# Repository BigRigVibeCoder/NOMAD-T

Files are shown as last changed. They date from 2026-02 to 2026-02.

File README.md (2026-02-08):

# NOMAD-T

**Autonomous Off-Road UGV — Engineering Design Package**

A field-hardened, 4WD skid-steer robot built from mass-produced scooter components. Designed for outdoor autonomy in unstructured terrain.

> **Architecture Lock (Rev 4.0):** Rigid 2040 frame, 4× Ninebot G30 hub motors, 36V Li-Ion, Odroid H4 Ultra.

---

## Versions

| Version | Codename | Purpose | Motors | Budget | Status |
|:---|:---|:---|:---|:---|:---|
| **Mk.0 "Scrapper"** | Alpha | Cheap pavement testbed | 4× Hoverboard 6.5" | ~$460 | **ACTIVE** |
| **Mk.1 "Nomad"** | Release | Field-hardened, weatherproof | 4× Ninebot G30 | ~$1,500 | Design Complete |

---

## Key Specifications

| Parameter | Value |
|:---|:---|
| **Drivetrain** | 4× Ninebot Max G30 Rear Hub Motors (Direct Drive) |
| **Frame** | 2040 V-Slot Aluminum Extrusion, 700 × 320mm |
| **Wheels** | 10" G30 Pneumatic (60/70-6.5), Tubeless |
| **Suspension** | None (Rigid) — Pneumatic tires provide damping |
| **Compute** | Odroid H4 Ultra (Intel i3-N305, 8C, DDR5) |
| **Sensors** | RPLiDAR C1, OAK-D Lite, 4× Sharp IR, BNO085 IMU |
| **Power** | 10S3P Li-Ion (36V), DDR-60L-15 DC-DC (17V Logic) |
| **Safety** | 60A MIDI Fuse, E-Stop, Arduino Watchdog, Contactor |
| **Enclosure** | Apache 3800 (IP65) on Vibration Isolation Bobbins |
| **Weight** | ~19 kg |
| **Est. Cost** | ~$1,600 |

---

## Project Structure

```
00_ALPHA/          Mk.0 "Scrapper" prototype specs & BOM
01_PROTOCOLS/      Documentation standards & naming conventions (HM-PRO)
02_CATALOG/        Mk.1 component specs, BOMs, trade studies (HM-CAT)
03_OPERATIONS/     Build guides, safety manual, checklists (HM-OPS)
04_ASSETS/         Images, renders, CAD models (HM-AST)
05_RESEARCH/       Analysis, whitepapers, CDR findings (HM-RES)
06_ENGINEERING/    Schematics, tools, source code (HM-DWG/SRC)
```

---

## Document Index

### Alpha (Mk.0 "Scrapper")
| ID | Title |
|:---|:---|
| HM-ALPHA-001 | [Alpha Prototype Spec](00_ALPHA/HM-ALPHA-001_spec.md) |
| HM-ALPHA-002 | [Alpha BOM / Shopping List](00_ALPHA/HM-ALPHA-002_bom.md) |

### Protocols
| ID | Title |
|:---|:---|
| HM-PRO-001 | [Documentation Standards](01_PROTOCOLS/HM-PRO-001_doc_standards.md) |

### Specifications (Catalog)
| ID | Title |
|:---|:---|
| HM-CAT-001 | [Master Design (Phase 1)](02_CATALOG/HM-CAT-001_master_design.md) |
| HM-CAT-002 | [Shopping List](02_CATALOG/HM-CAT-002_shopping_list.md) |
| HM-CAT-003–008 | Sensor Datasheets (OAK-D, PZEM, IR, LiDAR, GNSS, IMU) |
| HM-CAT-009 | [Brain Core (Odroid H4 Ultra)](02_CATALOG/HM-CAT-009_brain_core_compute.md) |
| HM-CAT-010 | [Drivetrain (G30 Hub Motors)](02_CATALOG/HM-CAT-010_drivetrain_spec.md) |
| HM-CAT-011 | [Component Trade Studies](02_CATALOG/HM-CAT-011_cots_selection.md) |
| HM-CAT-012 | [Master Integration (Apache 3800)](02_CATALOG/HM-CAT-012_master_integration.md) |
| HM-CAT-013 | [Frame (Rigid 2040)](02_CATALOG/HM-CAT-013_frame_suspension.md) |
| HM-CAT-014 | [Electrical System (36V)](02_CATALOG/HM-CAT-014_electrical_system.md) |
| HM-CAT-015 | [Custom Parts (Motor Plate NMT-MP-001)](02_CATALOG/HM-CAT-015_custom_parts.md) |
| HM-CAT-016 | [Odroid H4 Ultra Datasheet](02_CATALOG/HM-CAT-016_odroid_h4_ultra_datasheet.md) |

### Operations
| ID | Title |
|:---|:---|
| HM-OPS-001 | [Build Manual](03_OPERATIONS/HM-OPS-001_build_manual.md) |
| HM-OPS-002 | [Safety Manual](03_OPERATIONS/HM-OPS-002_safety_manual.md) |
| HM-OPS-003 | [Pre-Flight Checklist](03_OPERATIONS/HM-OPS-003_preflight_checklist.md) |

### Research
| ID | Title |
|:---|:---|
| HM-RES-001 | [Nomad-T Concept Analysis](05_RESEARCH/HM-RES-001_nomad_t_analysis.md) |
| HM-RES-002 | [UGV Whitepaper](05_RESEARCH/HM-RES-002_ugv_whitepaper.md) |
| HM-RES-003 | [Pre-Build Research Questions (Rev 4.0)](05_RESEARCH/HM-RES-003_pre_build_research_questions.md) |
| HM-RES-004 | [Case Selection Study](05_RESEARCH/HM-RES-004_case_selection_study.md) |
| HM-RES-005 | [Critical Design Review (13 CDRs)](05_RESEARCH/HM-RES-005_critical_design_review.md) |
| HM-RES-006 | [Hub Motor Trade Study](05_RESEARCH/HM-RES-006_hub_motor_trade_study.md) |

### Engineering
| ID | Title |
|:---|:---|
| HM-DWG-001 | [Wiring Harness Schematic](06_ENGINEERING/01_SCHEMATICS/HM-DWG-001_wiring_harness.md) |

---

## Status

**Phase 1 Hardware Design: COMPLETE**
- All 13 Critical Design Reviews resolved
- Wiring harness schematic issued
- Documentation synchronized
- Ready for procurement and assembly

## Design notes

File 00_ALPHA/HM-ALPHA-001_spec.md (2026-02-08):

---
ID: HM-ALPHA-001
Status: ACTIVE
Version: Mk.0 "Scrapper"
Date: 2026-02-08
Role: Alpha Prototype Specification
Linked: HM-CAT-001 (Mk.1 Master)
---

# Nomad-T Mk.0 "Scrapper" — Alpha Prototype Specification

> [!NOTE]
> **Purpose:** Cheapest possible skid-steer testbed to prove the ROS 2 control stack, VESC CAN bus, and autonomy software BEFORE committing to the $1,500 Mk.1 field build.
>
> **Constraints:** Pavement only. No weatherproofing. Budget: **<$500.**

---

## 1. System Overview

| Parameter | Mk.0 "Scrapper" | Mk.1 "Nomad" (Future) |
|:---|:---|:---|
| **Motors** | 4× Hoverboard 6.5" (Salvaged) | 4× Ninebot G30 |
| **Tires** | 6.5" Solid Rubber | 10" Pneumatic |
| **Frame** | 2040 V-Slot (700×320mm) | Same |
| **Voltage** | 36V (10S) | Same |
| **VESCs** | 4× Flipsky 75100 | Same |
| **Compute** | Odroid H4 Ultra | Same |
| **Enclosure** | Open-top (no case) | Apache 3800 (IP65) |
| **Waterproofing** | ❌ None | ✅ IPX5 |
| **Ground Clearance** | ~50mm | ~89mm |
| **Weight** | ~14 kg | ~19 kg |
| **Budget** | **~$458** | ~$1,500 |

---

## 2. Motor: Hoverboard 6.5" BLDC (Salvaged)

### Sourcing
**Buy 2× broken hoverboards** from Facebook Marketplace, Craigslist, or thrift stores.

- **Target price:** $10-20 per board = **$20-40 total for 4 motors**
- **What breaks on hoverboards:** Battery (dead cells), main board (blown FETs), charger port. **Motors almost never fail.**
- **What you harvest:** 2× BLDC hub motors with tires, Hall sensor cables, phase wires

### Specs

| Spec | Value |
|:---|:---|
| **Type** | Brushless DC (BLDC), direct drive |
| **Power** | 250–350W rated |
| **Voltage** | 36V (10S) — Native! |
| **Torque** | ~12 Nm per motor |
| **Tire** | 6.5" solid rubber (bonded) |
| **Hall Sensors** | Yes (5-wire: VCC, GND, HA, HB, HC) |
| **Phase Wires** | 3× (Match or auto-detect in VESC Tool) |
| **Weight** | ~2.3 kg per motor+tire |

### VESC Compatibility

> [!TIP]
> Hoverboard motors are one of the most common VESC targets. VESC Tool has built-in motor detection that auto-configures phase order and Hall sensor mapping. **No manual configuration needed** — just run "Detect Motor" wizard.

---

## 3. Mounting Strategy

Hoverboard motors have **no external axle**. They bolt directly to a frame via 4× M4 threaded holes on the motor face.

### Option A: 3D Printed Bracket (Fastest)
- **Material:** PETG or Nylon (100% infill)
- **Design:** L-bracket bolting motor face to 2040 rail side slot
- **Lifespan:** ~50 hours. Fine for prototyping.
- **Cost:** ~$2 in filament

### Option B: Flat Aluminum Bracket (Durable)
- **Material:** 3mm aluminum flat bar
- **Design:** Bent L-bracket, drilled on both ends
- **Cost:** ~$5 from hardware store
- **Upgradeable:** Can use same bracket concept for Mk.1 motor plates

---

## 4. Electrical (Simplified)

The Mk.0 uses the **same 36V architecture** as Mk.1 but with simplified wiring:

| System | Mk.0 Approach | Mk.1 Equivalent |
|:---|:---|:---|
| **Battery** | Salvaged hoverboard 36V pack OR cheap e-bike 10S pack | Custom 10S3P |
| **Main Fuse** | 40A blade fuse (cheaper) | 60A MIDI fuse |
| **DC-DC** | DDR-60L-15 (17V) | Same |
| **Safety** | E-Stop + basic relay | Full safety chain |
| **CAN Bus** | Daisy chain (same) | Same |
| **Contactor** | Optional (can use E-Stop direct for <40A) | 100A Contactor |

### Simplified Wiring

```
Battery (36V) → Blade Fuse (40A) → E-Stop → Bus Bar
  ├── VESC 1 (Front Left)
  ├── VESC 2 (Front Right)
  ├── VESC 3 (Rear Left)
  ├── VESC 4 (Rear Right)
  └── DC-DC (17V) → Odroid H4 Ultra
```

---

## 5. What to Test on Mk.0

| Test | Goal | Pass Criteria |
|:---|:---|:---|
| **VESC Motor Detection** | All 4 motors detected | Spin freely, correct direction |
| **CAN Bus Daisy Chain** | All 4 VESCs communicate | `ros2 topic echo` shows all 4 |
| **Teleop (RC)** | Joystick controls skid steer | Smooth forward, reverse, turn |
| **Turn-in-Place** | Zero-radius turn on pavement | Completes 360° without slipping |
| **Odometry** | Hall sensor ticks = distance | Straight line ±5% over 10m |
| **E-Stop** | Kill switch works | Motors stop within 0.5s |
| **Watchdog** | Software crash = motors off | Unplug USB → motors stop |

---

## 6. Upgrade Path: Mk.0 → Mk.1

When Mk.0 has proven the software stack:

1. **Unbolt** hoverboard motors + 3D printed brackets
2. **Bolt on** G30 motor plates (NMT-MP-001)
3. **Slide in** G30 hub motors
4. **Swap** blade fuse → MIDI fuse holder
5. **Add** Apache 3800 case on bobbins
6. **Add** Contactor + full safety chain
7. **Replace** salvaged battery → proper 10S3P pack

**Everything else stays.** Frame, VESCs, Odroid, DC-DC, CAN — all identical.

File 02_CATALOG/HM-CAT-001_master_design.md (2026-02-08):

---
ID: HM-CAT-001
Status: ACTIVE
Role: Master Design Specification (Phase 1)
Date: 2026-02-07
Linked: HM-CAT-010, HM-CAT-012, HM-CAT-013, HM-CAT-014
---

# Nomad-T Phase 1 "Skid-Steer" Specification

> [!NOTE]
> **APPROVED DESIGN.** This document supersedes all previous concepts (Badger-M, Arrma, Suspension).
> **Objective:** Build a rugged, weatherproof, skid-steer field robot using mass-produced scooter components.

## 1. System Overview

*   **Architecture:** 4WD Skid-Steer (Tank Drive)
*   **Chassis:** Rigid 2040 Aluminum Extrusion with DiBond Shear Panels
*   **Drivetrain:** 4× Direct-Drive Hub Motors (Ninebot G30 Gen 2)
*   **Power:** 36V 10S3P Li-Ion (Swappable)
*   **Compute:** Odroid H4 Ultra (x86) + OAK-D Lite + RPLiDAR C1
*   **Target Mass:** ~18–22kg
*   **Payload:** ~10kg (Flat Deck)
*   **Speed:** ~25 km/h (Software limited)

## 2. Core Directives (from CDR)

1.  **"Golden Unit" Sourcing:** Use verified OEM/refurb parts for critical drivetrain components (G30 motors), not generic clones.
2.  **Unified Thermal Deck:** The Odroid and VESCs share a common 6mm aluminum armor plate for cooling and protection (CDR-4).
3.  **Vibration Isolation:** The electronics case (Apache 3800) is "floated" on rubber bobbins to protect components (CDR-3).
4.  **Hardware Safety:** Physical E-Stop loop, independent status LEDs, and hardware watchdog (CDR-6, CDR-12).

## 3. Subsystem Breakdown

### 3.1 Structure (HM-CAT-013)
*   **Rails:** 700mm long 2040 V-Slot (Silver).
*   **Width:** 320mm outer-to-outer.
*   **Panels:** 3mm DiBond (Aluminum Composite) side skins for shear strength.
*   **Waterproofing:** IP65 desired for case (IPX5 for motors).

### 3.2 Drivetrain (HM-CAT-010)
*   **Motors:** 4× Ninebot Max G30 Rear Hub Motors (350W nom / 800W peak).
*   **Tires:** 10" Pneumatic (60/70-6.5) Pre-installed.
*   **Mounting:** Custom 6mm Aluminum plates with 2mm fillet radii slots (CDR-2).

### 3.3 Electronics (HM-CAT-014 & HM-DWG-001)
*   **Voltage:** 36V Nominal (10S).
*   **Protection:** 60A MIDI Fuse (Main), 10A (Charge), 5A (DC-DC).
*   **Logic:** 17V regulated for Odroid (CDR-8).
*   **Control:** 4× Flipsky 75100 VESC via CAN Bus.

## 4. Bill of Materials Summary (Phase 1)

| Subsystem | Est. Cost | Status |
| :--- | :--- | :--- |
| **Drivetrain** (Motors, Plates) | ~$350 | Sourcing |
| **Structure** (Rails, Case, DiBond) | ~$150 | Sourcing |
| **Power** (Battery, Fuse, Wiring) | ~$200 | Sourcing |
| **Compute** (Odroid, RAM, WiFi) | ~$400 | Purchased |
| **Control** (VESCs, Arduino) | ~$300 | Sourcing |
| **Sensors** (LiDAR, Camera) | ~$250 | Sourcing |
| **Total** | **~$1,650** | **Under Budget ($2k)** |

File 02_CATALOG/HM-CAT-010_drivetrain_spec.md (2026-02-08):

---
ID: HM-CAT-010
Status: ACTIVE
Role: Drivetrain Specification
Date: 2026-02-07
Linked: HM-CAT-001 (Master), HM-CAT-013 (Frame)
---

# Drivetrain Specification

> [!NOTE]
> **Design Change:** Shifted from "Belt Drive Outrunner" to **Direct Drive Hub Motor** for reliability, waterproofing, and simplicity.

## 1. Selected Motor: Ninebot Max G30 (Gen 2)

*   **Type:** Brushless Direct Drive Hub Motor
*   **Position:** Rear Wheel (Drum brake compatible, though brake not strictly required)
*   **Voltage:** 36V Nominal (10S)
*   **Power:** 350W Nominal / 700W Peak
*   **Torque:** ~30 Nm peak per wheel (×4 = 120 Nm total)
*   **KV:** ~14 KV (High torque, low speed)
*   **Speed:** ~30 km/h unloaded at 36V

### 1.1 Sourcing Rules (The "Golden Unit" - CDR-1)
*   **Target:** OEM or High-Quality Refurb (MonsterScooterParts, reputable eBay pulls).
*   **Avoid:** "Front" wheels (no motor), "Lite" versions (G30L/LP).
*   **Connector:** 3× Phase (Bullet/Spade) + 5/6 pin Hall Sensor.
    *   *Action:* Likely need to re-terminate phase wires to 4mm Bullets or MR60 for VESC.

## 2. Tire Specification

*   **Size:** 10 inch (Nominal OD ~250mm)
*   **Format:** 60/70-6.5 Tubeless Pneumatic
*   **Pressure:** ~25-30 PSI (Lower for off-road traction)
*   **Self-Healing:** Many G30 tires come with internal sealant (gel layer). This is a **bonus** for field robustness.

## 3. Mounting Interface (CDR-2 Specification)

> [!CRITICAL]
> **Custom Part Required:** NMT-MP-001 Motor Plate

The G30 axle has a "Double-D" profile. It **cannot** be clamped in standard round mounts.

*   **Plate Material:** 6061-T6 Aluminum (6mm thick).
    *   *Upgrade Option:* 304 Stainless Steel (CDR-2 recommendation for fatigue).
*   **Axle Slot:** 12mm Round with 10mm Flats.
*   **Fillet Radius:** **R2.0mm minimum** in slot corners to prevent stress risers.
*   **Fastening:** Bolted to 2040 Extrusion end-face via 4× M5 screws.
*   **Anti-Rotation:** The tight-tolerance slot + torque washer prevents axle spin.

## 4. Performance Calculations

| Param | Value |
| :--- | :--- |
| **Simulated Speed** | ~25 km/h (Loaded) |
| **Traction Force** | ~400N (continuous) / ~1000N (peak) |
| **Climbing Grade** | >30% (Skid steer traction limited) |
| **Turn-in-Place** | Excellent (High torque, rigid chassis) |

## 5. Maintenance Schedule (CDR-1)

*   **Bearings:** 6001-2RS (Standard sealed).
    *   *Interval:* Check for play every 50km. Replace if gritty.
*   **Axle Nuts:** Check torque (tightness) every 10 hours of operation.
*   **Tire Pressure:** Check weekly.

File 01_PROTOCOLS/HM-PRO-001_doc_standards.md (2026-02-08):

# Protocol: HiveMind Documentation Standard
**ID:** HM-PRO-001
**Status:** ACTIVE
**Classification:** OPEN INTERNAL

## 1. Purpose
To establish a high-assurance, "Deep Tech" documentation framework that ensures traceability, version control compatibility, and ease of cognitive retrieval for the Nomad-T project.

## 2. Directory Structure (Johnny Decimal + Diataxis)
The project structure determines the *type* of information stored.

*   **01_PROTOCOLS (Reference - Laws)**
    *   Standards, conventions, and defining rigid rules.
    *   *Example:* This document (`HM-PRO-001`).
*   **02_CATALOG (Reference - Specs)**
    *   System Specifications, Bill of Materials (BOM), and "Recipes".
    *   *Example:* Master Design Specs, Shopping Lists.
*   **03_OPERATIONS (How-to - Guides)**
    *   Step-by-step instructions, assembly guides, and tutorials.
    *   *Example:* "How to mount the motor", "Wiring Guide".
*   **04_ASSETS (Media)**
    *   Binary assets, Images, CAD files, Drawings.
*   **05_RESEARCH (Explanation)**
    *   Whitepapers, Trade Studies, Analysis, and theoretical groundwork.
*   **06_ENGINEERING (Source)**
    *   Technical source files, Schematics, Firmware, and Python tools.
    *   *Example:* Wiring Diagrams (HM-DWG), Source Code (HM-SRC).

## 3. Identification System (HM-ID-XXX)
All documentation files must have a unique identifier in their filename to ensure traceability despite refactors.

**Format:** `HM-[TYPE]-[SEQ]_[snake_case_title].md`

### Types
*   **PRO:** Protocol (Standards, Rules)
*   **CAT:** Catalog (Specs, Parts)
*   **OPS:** Operations (Guides, Manuals)
*   **RES:** Research (Theory, Analysis)
*   **DWG:** Drawing (Schematics, Diagrams)
*   **SRC:** Source Code (Firmware, Software)
*   **AST:** Asset (Images, Models) - *Mandatory for release candidates*

### Sequence
*   3-Digit Integer (e.g., `001`, `002`).
*   Sequences are unique *per Type*.

## 4. Maintenance
*   **Docs-as-Code:** All docs are stored in the repo with the code/designs.
*   **Traceability:** Changes to design must reference the Protocol or Catalog ID they affect.
*   **Assets:** All assets must be numbered (HM-AST-XXX) to be referenced in specs.

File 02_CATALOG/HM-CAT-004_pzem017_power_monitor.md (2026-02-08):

---
ID: HM-CAT-004
Status: ACTIVE
Source: github.com/BigRigVibeCoder/HiveMind
---

# Component Specification: Main Power & Energy Monitor

**Role:** Metabolic Analysis (Voltage, Current, Power, Energy Consumption)

**Hardware:** Peacefair PZEM-017 (Industrial DC)

**Interface:** RS485 (via USB Adapter)

## 1. The Problem: Measuring "The Gulp"

The robot's motors draw power in violent spikes (0A to 20A in milliseconds).

- **INA219 (Standard):** Max 3.2A. **REJECTED.** It will burn out.

- **Voltage Dividers:** Inaccurate. Only gives voltage, not current.

We need a sensor that can handle **60A Continuous / 80A Peak** at **36V** (10S Li-Ion, 30–42V range).

## 2. The Solution: PZEM-017 (Industrial DC Meter)

*Best for Phase 2/3 "Coyote". Zero soldering. Includes USB Interface.*

### 2.1 Hardware Overview

- **Type:** DC Communication Box + External Shunt.

- **Range:** 0-300V, 0-300A (Configurable based on shunt).

- **Interface:** RS485 (Modbus-RTU).

- **Isolation:** High voltage side is opto-isolated from the communication side. (Protects the Odroid USB port from spikes).

### 2.2 Integration Strategy

1. **Shunt:** Bolt the **100A / 75mV Shunt** onto the **36V HV Bus**.

   - **Location:** Between the 60A MIDI Fuse and the Distribution Bus (see HM-DWG-001).

   - **Orientation:** "Load" side goes to contactor/VESCs.

2. **Sense Wires:** Run small wires from the Shunt screws to the PZEM-017 terminals.

3. **Data Link:**

   - **PZEM Side:** Connect wires to A and B terminals.

   - **Odroid Side:** Connect A/B wires to the **USB-to-RS485 Adapter** (Included in kit).

   - **Plug:** Plug USB into Odroid.

4. **Protocol:** Modbus-RTU. (Standard industrial protocol).

### 2.3 Why it wins

- **Robustness:** You can't fry it. The high current never touches the PCB, only the solid metal shunt.

- **Kit Completeness:** The high-end kit includes the USB adapter and the correct shunt.

## 3. Option B: The Embedded Solution (INA226) - DEPRECATED

*Best for Phase 0/1 or if space is extremely tight.* (Kept for reference only).

### 3.1 Hardware Overview

- **Type:** High-Side Current/Power Monitor Chip.

- **Resolution:** 16-Bit (Ultra precise).

- **Range:** Up to 36V. Current depends on the resistor you solder.

- **Interface:** I2C.

### 3.2 The "Ready-to-Roll" Module

Do not buy a bare chip. Buy the **WaveShare INA226 Module**.

- **Connector:** PH2.0 (Easy to wire).

- **Shunt:** usually 0.1 Ohm (Max 2A). **WARNING:** You must Desolder the stock shunt and solder a **0.002 Ohm** shunt to read 50A.

- **Wiring:** Requires connecting SDA/SCL to the Odroid's GPIO headers (Pins 3/5).

## 4. ROS 2 Integration (PZEM-017)

We write a Python Node (`power_monitor_node.py`) using `pymodbus`.

### 4.1 The Node Logic (Python)

```
import rclpy
from rclpy.node import Node
from sensor_msgs.msg import BatteryState
from pymodbus.client import ModbusSerialClient

class PowerMonitor(Node):
    def __init__(self):
        super().__init__('power_monitor')
        self.pub = self.create_publisher(BatteryState, '/sensor/battery', 10)
        # Port depends on your USB adapter (check ls /dev/ttyUSB*)
        self.client = ModbusSerialClient(port='/dev/ttyUSB1', baudrate=9600, timeout=1)
        self.timer = self.create_timer(1.0, self.read_power)

    def read_power(self):
        # Read Input Registers (0x0000 start, 4 registers)
        # Reg 0: Voltage (0.01V)
        # Reg 1: Current (0.01A)
        # Reg 2-3: Power/Energy
        rr = self.client.read_input_registers(0x0000, 4, slave=1)
        
        if not rr.isError():
            msg = BatteryState()
            msg.voltage = rr.registers[0] * 0.01
            msg.current = rr.registers[1] * 0.01
            msg.charge = float('nan') # We don't know % without a curve
            self.pub.publish(msg)
```

### 4.2 Output Topic

- **Topic:** `/sensor/battery`

- **Message:** `sensor_msgs/BatteryState`

  - `voltage`: 16.4 V

  - `current`: 12.5 A

  - `charge`: NaN

## 5. Bill of Materials

### The "Ironclad" Kit (PZEM)

| Component | Source | Est. Cost |
| --- | --- | --- |
| **PZEM-017 Master Kit** (Module + 50A/100A Shunt + USB-RS485) | Amazon / AliExpress | $25 - $35 |
| **12 AWG Wire** | Home Depot / Amazon | $5 |

**Total:** \~$35 for a bulletproof, fire-safe power metering system.

**Recommendation:** **Buy the PZEM-017 Kit.** It is the complete package for high-power monitoring without component hunting.

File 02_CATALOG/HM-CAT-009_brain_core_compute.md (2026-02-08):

---
ID: HM-CAT-009
Status: CRITICAL PATH — Order Immediately
Date: 2026-02-07
Ref: HM-CAT-016 (OEM Datasheet)
---

# Phase 0 Procurement: The Brain Core

**Objective:** Secure the computational heart of the robot.

---

## 1. The Core (Compute)

| Field | Value |
|:---|:---|
| **Item** | ODROID-H4 Ultra |
| **CPU** | Intel Core i3-N305 (8-Core, 3.8GHz Turbo) |
| **GPU** | 32 EUs Intel UHD Graphics |
| **Vendor** | Ameridroid (US) / Hardkernel (Global) |
| **Cost** | ~$230 |
| **Why** | Only SBC with x86 + AVX2 instructions for local LLM inference |

---

## 2. Memory (RAM) — MAXED OUT

| Field | Value |
|:---|:---|
| **Item** | Crucial 48GB DDR5 5600MHz CL46 SO-DIMM |
| **Model** | CT48G56C46S5 (single stick) |
| **Cost** | ~$140 |
| **Constraint** | Maximizes LLM context window |

---

## 3. Storage (SSD) — CONFIRMED

| Field | Value |
|:---|:---|
| **Item** | TEAMGROUP MP44L |
| **Model (1TB)** | TM8FPK001T0C101 |
| **Model (2TB)** | TM8FPK002T0C101 |
| **Cost** | ~$70–$120 |

> [!IMPORTANT]
> **Thermal Note:** The Odroid H4 Ultra M.2 slot supports PCIe Gen 3.0 x4 (~3,500 MB/s). This Gen 4 drive is backward compatible. The MP44L uses TLC NAND and is **DRAM-less** — critical for our sealed enclosure to prevent thermal throttling. Best performance-to-heat ratio available.

---

## 4. Network (WiFi 6E)

| Field | Value |
|:---|:---|
| **Item** | Intel AX210 WiFi 6E M.2 Card (Desktop Kit) |
| **Note** | Must include IPEX4 pigtails and antennas |

---

## 5. Case & Cooling

> [!WARNING]
> **CANCELLED:** ~~ODROID-H4 Case Type 3~~ and ~~Noctua NF-A9x14 fan~~.
> Per RQ-5.1 and CDR-4, the Odroid is mounted **inverted** into the **Apache 3800** case lid via the **Unified Thermal Deck** (6mm aluminum armor plate + 15mm copper thermal pedestal). No separate computer case or dedicated fan is needed.

| Field | Value |
|:---|:---|
| **Enclosure** | **Apache 3800** (shared with robot electronics) |
| **Thermal** | Unified Thermal Deck (see RQ-5.1 / CDR-4) |
| **Internal Fan** | 40mm Noctua (stirs internal air only — NOT primary cooling) |

---

## 6. Power Supply

### Bench / Lab Power
| Field | Value |
|:---|:---|
| **Adapter** | Dtk 19V 4.74A 90W Laptop Charger |
| **Tip Adapter** | 5.5x2.5mm Female → 5.5x2.1mm Male |

### Field Power (CDR-8)
| Field | Value |
|:---|:---|
| **Source** | Mean Well DDR-60L-15 (Trimmed to **17V**) |
| **Input** | 36V Battery (18–75V DC Range) |
| **Output** | 17V @ 4A (60W Max) |
| **Connection** | DC Barrel Jack 5.5×2.1mm |

---

## 7. Shopping Checklist

| Vendor | Component | Spec Check | Est. Price |
|:---|:---|:---|:---|
| Ameridroid | Odroid H4 Ultra | Verify "Ultra" (i3-N305) | $230.00 |
| ~~Ameridroid~~ | ~~Case Type 3~~ | **CANCELLED** — Unified Thermal Deck | ~~$15.00~~ |
| Amazon | Crucial 48GB DDR5 | CT48G56C46S5, Single Stick | $140.00 |
| Amazon | TEAMGROUP MP44L 1TB | TM8FPK001T0C101 | ~$70–$120 |
| Amazon | Intel AX210 Kit | Includes IPEX4 + Antennas | $25.00 |
| ~~Amazon~~ | ~~Noctua NF-A9x14 PWM~~ | **CANCELLED** — Thermal Deck cools | ~~$20.00~~ |
| Amazon | Dtk 19V 4.74A PSU | 5.5×2.1mm Plug (native) | $20.00 |
| | | **TOTAL** | **~$485–$535** |

---

## 8. Next Steps (While Shipping)

1. **Download OS:** Get the [Ubuntu 24.04 LTS Server ISO](https://ubuntu.com/download/server).
2. **Prepare Installer:** Flash the ISO to a USB stick using [BalenaEtcher](https://etcher.balena.io/).

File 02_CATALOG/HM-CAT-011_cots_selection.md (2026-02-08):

---
ID: HM-CAT-011
Status: ACTIVE
Role: Component Selection Rationale (Phase 1)
Date: 2026-02-07
Linked: HM-CAT-010, HM-RES-005
---

# Component Selection Rationale (Phase 1)

> [!NOTE]
> **Why we changed everything.**
> The initial "Badge-M" concept (RC Truck parts) was rejected during Research for being water-permeable, complex, and maintenance-heavy. The Phase 1 design prioritizes **Reliability** and **Sealing**.

## 1. Drivetrain: Hub Motors vs. Belt Drive

| Feature | G30 Hub Motor (Selected) | RC Belt Drive (Rejected) |
| :--- | :--- | :--- |
| **Sealing** | IPX5 (Sealed Drum) | Open (Belts collect mud) |
| **Complexity** | 1 Moving Part | ~20 Parts (Pulley, Belt, Mount, Axle, Bearings) |
| **Torque** | 30Nm (Direct) | ~4Nm (Gearing required) |
| **Maintenance** | Zero | High (Belt tension, debris clearing) |
| **Cost** | $60/corner | ~$120/corner |

**Decision:** **Ninebot G30 Hub Motors.** They solve the "Rasputitsa" mud problem by having no external linkage to jam.

## 2. Chassis: 2040 Extrusion vs. Suspension

| Feature | Rigid 2040 "Skid" (Selected) | Trailing Arm Susp (Rejected) |
| :--- | :--- | :--- |
| **Simplicity** | Bolt-together | Complex geometry, pivots, shocks |
| **Rigidity** | Extreme (Box frame) | Flexible (Compliance issues) |
| **Payload** | High (Static load) | Limited by spring rates |
| **Terrain** | "Tank" style | Baja style |

**Decision:** **Rigid 2040 Frame.** For a slow-moving (25km/h) field robot, pneumatic tires provide sufficient damping. Suspension adds unwarranted complexity for Phase 1.

## 3. Power: 36V (10S) vs. 22V (6S)

| Feature | 36V Architecture (Selected) | 22.2V RC LiPo (Rejected) |
| :--- | :--- | :--- |
| **Efficiency** | Higher (Lower current for same power) | Lower (High current heat) |
| **Compatibility** | Native to G30 components | Requires boost or specialized motors |
| **Availability** | Massive e-bike/scooter ecosystem | RC Hobby specific |
| **Safety** | Steel-cased 18650s | Soft-pouch LiPos (Fire risk) |

**Decision:** **36V System.** Aligns with industrial/scooter standards and reduces I²R losses in the wiring.

## 4. Compute: Odroid H4 Ultra vs. Jetson

**Decision:** **Odroid H4 Ultra.**
*   **Why x86?** Superior compatibility with ROS 2, Docker, and standard Linux tools compared to ARM (Jetson).
*   **Why Ultra?** 8 Cores provide headroom for heavy V-SLAM (Visual SLAM) and navigation stacks without bogging down.

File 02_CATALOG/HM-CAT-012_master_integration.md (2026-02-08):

---
ID: HM-CAT-012
Status: ACTIVE
Role: Master Integration Specification
Date: 2026-02-07
Linked: HM-CAT-001, HM-CAT-009, HM-CAT-014
---

# Master Integration Specification

> [!NOTE]
> **Updated for Phase 1.** Defines the physical integration of all subsystems into the Apache 3800 chassis.

## 1. Primary Enclosure: Apache 3800 (CDR-3)

*   **Model:** Apache 3800 Water-Resistant Protective Case (Black)
*   **Dimensions (Ext):** 415 × 328 × 173 mm
*   **Dimensions (Int):** 378 × 268 × 154 mm (Base Depth: 105mm)
*   **Modifications:**
    *   Lid removed and replaced with **Unified Thermal Deck** (6mm Al Plate).
    *   Base drilled for wire glands (cable ingress) and mounting bobbins.
*   **Mounting:** 4x M5 Vibration Isolation Bobbins (Shore 40A).

## 2. Power Source: 10S3P Li-Ion (36V)

*   **Architecture:** 10 Series, 3 Parallel
*   **Cell Type:** 18650 High-Discharge (Samsung 25R or similar)
*   **Capacity:** ~7.5Ah - 9.0Ah (depending on cell) -> **Updated Target: 10Ah+**
*   **Dimensions:** ~200mm × 80mm × 70mm block
*   **Connector:** XT90-S Anti-Spark
*   **Placement:** Floor of Apache 3800 (Right Side), secured with strap plate (CDR-9).

## 3. Unified Thermal Deck (CDR-4)

The "Lid" of the case is a functional heatsink.

| Component | Mounting | Notes |
| :--- | :--- | :--- |
| **Odroid H4 Ultra** | Inverted | CPU contacts Copper Pedestal (15mm) -> Thermal Pad -> Deck |
| **VESC 75100 (x4)** | Inverted | Flat side bolted to Deck bottom |
| **Status LEDs** | Panel Mount | Rear facing on box edge or separate panel |

## 4. Sensor Placement

*   **RPLiDAR C1:** Mounted on short mast or direct to front deck. Height: >300mm from ground.
*   **OAK-D Lite:** Camera mast or bracket.
*   **GPS/Compass:** Mast (keep away from Motors/High Current wires).

## 5. Ground Clearance

*   **Wheel Radius:** 125mm (10" Tire)
*   **Axle Height:** 125mm
*   **Frame Rail Bottom:** Axle Height - 40mm (Profile) = ~85mm
*   **Result:** **~89mm** clearance under rails. Excellent for gravel/grass.

## 6. Mass Estimate

| Subsystem | Mass |
| :--- | :--- |
| **Structure (Rails/Plate)** | 4.0 kg |
| **Drivetrain (Motors x4)** | 8.8 kg (2.2kg ea) |
| **Battery (10S3P)** | 2.5 kg |
| **Electronics + Case** | 3.5 kg |
| **Total** | **~18.8 kg** |

Within the 20-25kg target for manageable field deployment.

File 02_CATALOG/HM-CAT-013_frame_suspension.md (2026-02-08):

---
ID: HM-CAT-013
Status: ACTIVE
Role: Frame Specification
Date: 2026-02-07
Linked: HM-CAT-010, HM-CAT-012
---

# Frame Specification (2040 Rigid)

> [!NOTE]
> **Simplicity First.** The suspension design was rejected due to complexity and weight. We use a rigid "skid" frame relying on large pneumatic tires for damping.

## 1. Main Structure

*   **Profile:** 2040 V-Slot Aluminum Extrusion (Silver or Black)
*   **Length:** 700mm (Side Rails)
*   **Width:** 320mm (Outer-to-Outer rail spacing)
*   **Crossmembers:**
    *   2040 Profile for rigidity.
    *   Positioned at Front, Rear, and Center (Battery/Load support).
*   **Joinery:** Interior Corner Brackets + T-Plates for rigidity.

## 2. Shear Panels (CDR-9)

*   **Material:** 3mm DiBond (Aluminum Composite Panel)
*   **Role:** Structural "Shear Web" to prevent parallelogramming.
*   **Mounting:** Bolted to the side of the 2040 rails.
*   **Aesthetics:** Dark Gray / Black matte finish.

## 3. Motor Interface (NMT-MP-001)

*   **Plates:** 6mm Aluminum (6061-T6)
*   **Location:** Bolted to the *front and rear faces* of the side rails.
*   **Function:** Holds the G30 axle flats (CDR-2). Doubles as a structural corner gusset.

## 4. Vibration Isolation (CDR-3)

*   **Mounts:** 4x M5 Rubber Bobbins (Shore 40A)
*   **Location:** Top of the 2040 rails.
*   **Payload:** Carries the Apache 3800 case.
*   **Purpose:** Decouples high-frequency chassis vibration (motor/terrain) from sensitive electronics (Odroid/HDD).

## 5. Cut List (Phase 1)

| Part | Profile | Length | Qty |
| :--- | :--- | :--- | :--- |
| **Side Rails** | 2040 | 700mm | 2 |
| **Crossbeams** | 2040 | 240mm | 4 |
| **Motor Plates** | 6mm Al | Custom | 4 |
| **Shear Panels** | 3mm DiBond | 700x120mm | 2 |

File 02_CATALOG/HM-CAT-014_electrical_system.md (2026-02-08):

---
ID: HM-CAT-014
Status: ACTIVE
Role: Electrical System Specification
Date: 2026-02-07
Linked: HM-DWG-001 (Schematic)
---

# Electrical System Specification

> [!CAUTION]
> **Safety Critical.** Follow HM-DWG-001 Schematic exactly.

## 1. High Voltage (HV) Bus

*   **Nominal Voltage:** 36V DC
*   **Chemistry:** Li-Ion (10S)
*   **Max Voltage:** 42.0V
*   **Min Voltage:** 30.0V (Cutoff)
*   **Main Fuse:** 60A MIDI Fuse (Bolt-down, >58V Rated)
*   **Connector:** XT90-S Anti-Spark

## 2. Low Voltage / Logic

*   **Source:** Mean Well DDR-60L-15 DC-DC Converter
*   **Input:** 18-75V DC
*   **Output:** 15V (Trimmed to **17V** per CDR-8)
*   **Capacity:** 60W (4A)
*   **Loads:**
    *   Odroid H4 Ultra (17V)
    *   USB Peripherals (5V via Odroid)
    *   Arduino Nano (5V via USB)

## 3. Safety Systems (CDR-6)

*   **Emergency Stop:**
    *   Physical mushroom button (NC).
    *   Breaks the **coil circuit** of the main contactor.
    *   Does NOT switch high current directly.
*   **Watchdog:**
    *   Arduino Nano monitors heartbeat from ROS.
    *   If lost, kills relay -> kills contactor.
*   **Braking:**
    *   200W 8Ω Brake Resistor on HV Bus.
    *   Triggered by VESC over-voltage protection (CDR-5).

## 4. Communication

*   **CAN Bus:**
    *   Daisy-chain topology (CDR-7).
    *   Shielded Twisted Pair (STP).
    *   120Ω Terminator at last node.
*   **USB:**
    *   Internal USB 2.0 to Arduino.
    *   External USB 3.0 to Sensors.

## 5. Wiring Standards

*   **HV (Battery -> Dist):** 10 AWG Silicone (Red/Black)
*   **HV (Dist -> VESC):** 14 AWG Silicone
*   **Motor Phase:** 16 AWG (or OEM Motor Wire)
*   **Logic Power:** 18-20 AWG
*   **Signal/CAN:** 22-24 AWG Twisted

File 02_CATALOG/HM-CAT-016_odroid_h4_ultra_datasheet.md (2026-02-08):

---
ID: HM-CAT-016
Status: ACTIVE
Date: 2026-02-07
Role: OEM Datasheet Extract — Odroid H4 Ultra
Source: Hardkernel "ODROID H4 Series Introduction" PDF (2024)
Linked: HM-CAT-009
---

# Odroid H4 Ultra — OEM Specification Extract

> [!NOTE]
> This document extracts the **engineering-critical specifications** from the official Hardkernel datasheet PDF. Full benchmarks and marketing content are omitted. Refer to the original PDF for complete data.

---

## 1. Processor

| Spec | Value |
|:---|:---|
| **CPU** | Intel Core i3 Processor N305 |
| **Codename** | Alder Lake-N |
| **Microarchitecture** | Gracemont |
| **Cores / Threads** | 8C / 8T |
| **Cache** | 6 MB |
| **AVX2** | Yes |
| **TDP (Balanced Mode)** | **15W** |
| **Single-Thread Burst** | **3.8 GHz** |
| **All-Core Boost (UP Mode)** | **3.0 GHz** |
| **Tj (Max Junction Temp)** | ~105°C (throttle begins at Tj − 5°C) |

---

## 2. Power Consumption (MEASURED by Hardkernel)

> [!CAUTION]
> **These are the authoritative numbers.** All thermal design calculations must use these values, NOT the 65W figure used in earlier analysis.

| Condition | Power Draw |
|:---|:---|
| Power Off | 0.2W |
| Suspend to RAM | 0.9–1.2W |
| Headless Idle (ASPM Auto) | **2.8W** |
| Desktop GUI Idle | **6.2W** |
| 4K YouTube Playback | 15.4W |
| WebGL Demo | 16.4W |
| CPU Stress (Balanced, PL4=30000) | **20.5W** |
| CPU + GPU Stress (Balanced) | **19–22W** |
| WebGL + CPU Stress | 21.6W |
| **UP Mode Max (PL4=0, active load)** | **34+W** |
| UP Mode Idle | Same as Balanced idle |

**Key insight:** In Unlimited Performance mode, idle power is identical to Balanced. The 34W max occurs ONLY during sustained all-core turbo boost under load.

---

## 3. Thermal Behavior

| Parameter | Value |
|:---|:---|
| Passive heatsink (Balanced mode) | **Sufficient — no fan needed** |
| Active cooling (UP mode) | Fan required to prevent throttle |
| Fan temp reduction | **25–30°C** below passive-only |
| Throttle behavior | CPU auto-throttles ~5°C below Tj max |
| Fan connector | 12V PWM 4-pin (standard PC) |
| Compatible fans | 92×15mm slim OR 92×25mm thick |

> [!IMPORTANT]
> **Hardkernel explicitly states:** "You do not need a fan in Balanced mode." The stock passive heatsink is designed to handle 15W TDP without active cooling. UP mode (34W) requires a fan to avoid thermal throttling.

---

## 4. Physical Dimensions

| Parameter | Value |
|:---|:---|
| **Board dimensions** | **120mm × 120mm** (4.7" × 4.7") |
| **Board + heatsink height** | **~47mm** |
| **Form factor change** | +10mm per side vs H3 series (was 110×110mm) |

> [!WARNING]
> HM-CAT-009 and HM-CAT-012 reference 110×110mm board dimensions — those are the H3 series. The H4 Ultra is **120×120mm**. The Unified Thermal Deck plate must accommodate this larger footprint.

---

## 5. Power Input

| Parameter | Value |
|:---|:---|
| DC Jack | 5.5mm outer / 2.1mm inner (positive center) |
| **Input voltage range** | **14V – 20V** |
| Recommended PSU (no HDDs) | 15V / 4A (60W) |
| Recommended PSU (with HDDs) | 19V / 7A (133W) |

**For Nomad-T:** Our DC-DC targets 19V output from 36V battery. The Odroid accepts 14–20V. At 19V, current draw at max load (34W UP) = 34/19 = **1.8A.** At 22W balanced stress = **1.16A.** Wire gauge requirements are minimal.

---

## 6. Memory

| Parameter | Value |
|:---|:---|
| Slots | 1× DDR5 SO-DIMM (single channel) |
| Speed | Up to 4800 MT/s (5600 MT/s modules run at 4800) |
| **Max validated** | **48 GB** (DDR5 SO-DIMM) |
| DDR4 compatible? | **No** — DDR5 only |

---

## 7. Storage

| Parameter | Value |
|:---|:---|
| M.2 NVMe | 1× PCIe Gen 3 x4 (NGFF-2280) |
| M.2 SATA | Compatible (uses 1 PCIe lane) |
| SATA III | 4 ports (H4 Ultra) |
| eMMC | 1× socket (bootable) |

---

## 8. I/O Ports

| Port | Count | Notes |
|:---|:---|:---|
| USB 3.0 | 2 | |
| USB 2.0 | 2 + 3 (on expansion header) | |
| 2.5 GbE Ethernet | 2 | Intel I226-V |
| HDMI 2.0 | 1 | 4K@60Hz |
| DisplayPort 1.2 | 2 | 4K@60Hz each |
| Audio out/in | 3.5mm jacks | |
| SPDIF out | 1 | |

---

## 9. Expansion Header (24-pin, 2.54mm pitch)

| Signal | Count |
|:---|:---|
| I2C | 2× (SCL/SDA, 3.3V IO) |
| UART | 1× (TXD/RXD/RTS/CTS, 3.3V IO) |
| USB 2.0 | 3× |
| HDMI-CEC | 1× |
| External Power Button | 1× |
| DC 5V | 1× |
| DC 3.3V | 1× |
| GND | 5× |

---

## 10. Other Features

| Feature | Detail |
|:---|:---|
| **Dual BIOS** | Yes (H4 Ultra) — backup via jumper |
| **TPM 2.0** | fTPM enabled |
| **Certifications** | FCC / CE / KC / RoHS |
| **Price** | $239 (board only) |

---

## 11. Connector Heights (Critical for Thermal Deck)

The board's tallest components are the I/O connectors on the rear edge:

| Component | Approximate Height |
|:---|:---|
| RJ45 Ethernet × 2 (stacked) | **~15mm** |
| USB 3.0 × 2 | **~15mm** |
| USB 2.0 × 2 | **~13mm** |
| HDMI 2.0 | **~11mm** |
| DisplayPort × 2 | **~10mm** |
| DC Jack | **~11mm** |
| CPU Die (exposed) | **~1mm** above PCB |

**Gap to bridge:** When board is inverted, the Ethernet/USB jacks create a **~14mm gap** between the CPU die and the cooling plate. This is why the Unified Thermal Deck requires a **15mm copper thermal pedestal** (see RQ-5.1 in HM-RES-003).

---

*Extracted from Hardkernel official PDF, "Introducing the ODROID-H4, H4+ and H4 Ultra" (April 2024)*
*Catalog document prepared: 2026-02-07*

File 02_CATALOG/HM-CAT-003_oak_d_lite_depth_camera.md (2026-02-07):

---
ID: HM-CAT-003
Status: ACTIVE
Source: github.com/BigRigVibeCoder/HiveMind
---

# Component Specification: Luxonis OAK-D Lite

**Role:** Primary Vision & Depth Perception Unit\
**Architecture:** Edge AI Coprocessor (VPU)\
**Interface:** USB 3.0 (Type-C)\
**Data Protocol:** XLink (Serialized Data Packets)

## 1. Core Concept: "The Smart Eye"

The OAK-D Lite differs from a standard camera in that it processes raw visual data **on-device** using the Intel Movidius Myriad X VPU.

- **Input:** Raw image data from 3 onboard sensors.

- **Processing (On-Device):**

  - **Stereo Depth:** Calculates disparity between Left/Right cameras to generate a Z-depth map.

  - **Neural Inference:** Runs `.blob` models (YOLO, MobileNet) to detect objects.

  - **Spatial Calculation:** Combines Depth + AI to calculate the exact X, Y, Z metric coordinates of an object relative to the camera.

- **Output:** Lightweight Metadata packets (e.g., `"Cup detected at X:20cm, Y:5cm, Z:50cm"`).

**Engineering Implication:** The Host Computer (Odroid) does **zero** image processing. It simply receives a stream of coordinates, keeping the CPU free for LLM and Motion Control tasks.

## 2. Hardware Architecture

### 2.1 Sensors

- **RGB Camera (Center):** 13MP (Sony IMX214). Used for AI inference and color video streaming.

- **Stereo Cameras (Left/Right):** 640x480 (OmniVision OV7251). Global Shutter (excellent for robotics/motion). Used for depth calculation.

- **Focus Type:** **Fixed-Focus** (Selected for K9 to prevent vibration damage).

### 2.2 The Compute Engine (VPU)

- **Chip:** Intel Movidius Myriad X.

- **Performance:** 4 TOPS (Trillions of Operations Per Second).

- **Power Consumption:** 2.5W - 5W (Powered via USB-C).

## 3. Data Interface & Protocol

While physically connected via USB, the device does not act like a simple serial port (UART). It uses **XLink**, a high-speed protocol that wraps data streams.

### 3.1 The "Output Pipelines"

You can configure the camera to output multiple streams simultaneously.

1. **NN Output (Metadata - Very Low Bandwidth):**

   - **Payload:** Array of Detections.

   - **Structure:** `[Label_ID, Confidence, BoundingBox_Rect, Spatial_X, Spatial_Y, Spatial_Z]`.

   - **Usage:** Primary input for K9's "Brain" and "Reflex" layers.

2. **Depth Map (Video - Medium Bandwidth):**

   - **Payload:** 16-bit Grayscale Video.

   - **Usage:** Fed into ROS 2 `Nav2` for obstacle costmaps.

3. **RGB Video (Video - High Bandwidth):**

   - **Payload:** NV12 or MJPEG encoded video.

   - **Usage:** Streaming to the Operator's HUD (Foxglove Studio).

### 3.2 Example Data Packet (JSON Representation)

*What the Odroid receives when the camera sees a person:*

```
{
  "detections": [
    {
      "label": "person",
      "confidence": 0.98,
      "spatialCoordinates": {
        "x": 105.0,  // mm right of center
        "y": -50.0,  // mm below center
        "z": 1500.0  // mm distance (1.5 meters away)
      },
      "boundingBox": {
        "xmin": 0.4, "ymin": 0.2, "xmax": 0.6, "ymax": 0.8
      }
    }
  ]
}
```

## 4. ROS 2 Integration (`depthai_ros_driver`)

The OAK-D Lite has a native ROS 2 driver that handles the XLink communication and publishes standard ROS messages.

| ROS 2 Topic | Message Type | Description |
| --- | --- | --- |
| `/oak/nn/spatial_detections` | `depthai_ros_msgs/SpatialDetectionArray` | **The Critical Feed.** Contains the 3D coordinates of objects. |
| `/oak/rgb/image_raw` | `sensor_msgs/Image` | Visual video feed. |
| `/oak/stereo/image_raw` | `sensor_msgs/Image` | Depth heat map. |
| `/oak/points` | `sensor_msgs/PointCloud2` | Full 3D point cloud (Heavy bandwidth, use sparingly). |

## 5. Limitations & Constraints

1. **Minimum Depth:** \~20cm. Objects closer than this cannot be seen in 3D (Blind spot).

   - *Mitigation:* This is why we added the "Chin" sensor (ToF) for the K9.

2. **Low Light:** Passive stereo depth requires light. It fails in pitch blackness.

   - *Mitigation:* We added the "Sun" module (LEDs) or rely on LIDAR in the dark.

3. **USB Bandwidth:** Streaming 4K Video + Point Clouds requires USB 3.0.

   - *Constraint:* Ensure it is plugged into the **Blue** USB ports on the Odroid.

## 6. Summary for Engineers

The OAK-D Lite acts as a **Sensor-to-Object Gateway**.

- **Input:** Reality.

- **Output:** Coordinates (`XYZ`).

- **Load:** &lt; 5% CPU usage on the host computer.

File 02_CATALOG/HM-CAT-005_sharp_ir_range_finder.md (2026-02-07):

---
ID: HM-CAT-005
Status: ACTIVE
Source: github.com/BigRigVibeCoder/HiveMind
---

# Component Specification: IR Proximity Sensors (The "Whiskers")

**Role:** Close-Range Blind Spot Detection (Chin/Side/Rear)\
**Hardware:** Sharp GP2Y0A21YK0F (10-80cm)\
**Interface:** Analog Voltage (Requires ADC Adapter)\
**Status:** **APPROVED**

## 1. Core Concept: "The Virtual Bumper"

While the LIDAR sees walls and the OAK-D sees people, neither can see a table leg 5cm from the robot's hip. IR Proximity sensors act as "Whiskers."

- **Technology:** Infrared Triangulation.

- **Range:** 10cm to 80cm.

- **Behavior:** It outputs a voltage (0.4V - 3.1V) proportional to distance.

- **Why not Ultrasonic?** Ultrasonic is slow (speed of sound latency) and has wide cones (ghost echoes). IR is a tight beam and instant.

## 2. Hardware Architecture

### 2.1 The Sensor (Sharp IR)

- **Part:** **Sharp GP2Y0A21YK0F**.

- **Beam Width:** Narrow.

- **Refresh Rate:** \~25Hz (40ms).

- **Connection:** 3-Wire (VCC, GND, Signal).

### 2.2 The Interface (The ADC Bridge)

**Hardware:** **NOYITO USB 10-Channel 12-Bit AD Data Acquisition Module** (STM32 based).

- **Chipset:** STM32F103C8T6 + CH340 (USB Serial).

- **Channels:** 10 Analog Inputs (IN0 - IN9).

- **Resolution:** 12-Bit (0-4096 values).

- **Voltage Range:** 0V - 3.3V (Matches Sharp IR output perfectly).

**Wiring Diagram:**

| Sharp Sensor Wire | Connection Point | NOYITO Pin |
| --- | --- | --- |
| **Red (VCC)** | Power Rail | **5V / 3.3V** (Use 5V for Sharp) |
| **Black (GND)** | Ground Rail | **GND** |
| **Yellow (Signal)** | Analog Input | **IN0 - IN3** |

*Note:* The Sharp sensor requires 5V power, but outputs &lt;3.3V signal. Verify the NOYITO board passes 5V from USB to a VCC pin, or wire the Red wires to the robot's 5V rail (from the Power Server or Odroid USB 5V line).

### 2.3 Proposed Placement (x4)

1. **Chin (Down/Forward):** Detects stair edges (backup to ToF). -&gt; **IN0**

2. **Left Hip:** Detects doorframes during strafing. -&gt; **IN1**

3. **Right Hip:** Detects doorframes during strafing. -&gt; **IN2**

4. **Rear (Tail):** Detects obstacles when backing up. -&gt; **IN3**

## 3. Data Interface & Protocol

### 3.1 The "Voltage-to-Distance" Curve

The Sharp sensor is **Non-Linear**.

- 80cm = 0.4V

- 10cm = 3.1V

- **Math:** We use a lookup table or a power function in software to convert Voltage -&gt; Meters.

  - *Formula:* $Distance (cm) = 27.86 \\times (Voltage)^{-1.15}$

### 3.2 The Serial Output (NOYITO Protocol)

The module streams data as text lines containing raw ADC values.

- *Example Output:* `1024, 2048, 450, 12, ... \n`

- *Parsing:* Split string by comma -&gt; Map index to Sensor Location.

## 4. ROS 2 Integration

We write a simple Python Node (`proximity_node.py`) to read the ADC and publish `Range` messages.

### 4.1 The Node Logic (Python)

```
import serial
import math

# Configuration
PORT = '/dev/ttyUSB0'
BAUD = 115200 # Standard for STM32 USB dumps

def adc_to_cm(adc_value):
    # 1. Convert 12-bit Int (0-4096) to Voltage (0-3.3V)
    voltage = (adc_value * 3.3) / 4096.0
    
    # 2. Prevent divide by zero / math errors at extreme low voltage
    if voltage < 0.4: return 80.0
    
    # 3. Apply Sharp IR Formula
    distance = 27.86 * (voltage ** -1.15)
    return max(10.0, min(80.0, distance)) # Clamp to sensor limits

def read_loop():
    with serial.Serial(PORT, BAUD, timeout=1) as ser:
        while True:
            line = ser.readline().decode('utf-8').strip()
            # Expecting CSV: "val1, val2, val3..."
            if line:
                values = [int(x) for x in line.split(',') if x.isdigit()]
                if len(values) >= 4:
                    chin_dist = adc_to_cm(values[0])
                    left_dist = adc_to_cm(values[1])
                    right_dist = adc_to_cm(values[2])
                    rear_dist = adc_to_cm(values[3])
                    
                    # Publish to ROS Topic /sensor/ir_range/...
```

### 4.2 Nav2 Integration

We add these to the **Local Costmap**.

- **Layer:** `RangeSensorLayer`.

- **Behavior:** If the Rear IR sees an object at 20cm, it marks a "Lethal Obstacle" behind the robot. The planner will refuse to back up.

## 5. Bill of Materials (The Kit)

| Component | Source | Est. Cost |
| --- | --- | --- |
| **Sharp GP2Y0A21YK0F (x4)** | Amazon / Pololu | $40 ($10 ea) |
| **JST-PH Cables** | Included with Sensor | $0 |
| **NOYITO 10-CH USB ADC** | Amazon | $15 |
| **3D Printed Mounts** | Custom (Simple bracket) | $0 |

**Total:** \~$55 for 360-degree close-range protection.

## 6. Engineering Verdict: APPROVED

This fills the "Blind Spot" gap left by the OAK-D (min range 20cm) and LIDAR (can't see glass/black surfaces well). It is cheap insurance for your expensive legs.

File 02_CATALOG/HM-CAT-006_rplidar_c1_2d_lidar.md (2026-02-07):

---
ID: HM-CAT-006
Status: ACTIVE
Source: github.com/BigRigVibeCoder/HiveMind
---

# Component Specification: Slamtec RPLIDAR C1

Role: Primary Indoor Localization & Mapping Sensor

Architecture: DTOF (Direct Time-of-Flight) Laser Scanner

Interface: USB 2.0 (via CP210x Bridge)

Scanning Frequency: 10 Hz (Adjustable 5-12 Hz)

## 1. Core Concept: "The 360° Ruler"

The RPLIDAR C1 is a significant upgrade from the older A1/A2 series. Instead of using a camera to triangulate a laser dot (which is bulky and sensitive to light), the C1 measures the time it takes for a laser pulse to bounce back.

- **Technology:** Direct Time-of-Flight (DTOF).

- **Field of View:** 360° (Full rotation).

- **Range:** 0.05m to 12m.

- **Resolution:** &lt; 2cm accuracy.

- **Environment:** **Outdoor Ready** (40,000 Lux resistance). This is the key reason we chose the C1 over the A1—it won't go blind on a sunny driveway.

**Engineering Implication:** Unlike the A1, the C1 is a sealed, compact unit with no external belt. This makes it far more durable for a walking robot that experiences vibration and dust.

## 2. Hardware Architecture

### 2.1 Physical Characteristics

- **Dimensions:** 55.6mm x 59.8mm x 41.3mm. (Tiny footprint).

- **Weight:** 110g. (Minimal impact on the robot's center of gravity).

- **Motor:** Brushless (Long lifespan, low noise).

### 2.2 Data Output

- **Sample Rate:** 5,000 points per second.

- **Angular Resolution:** 0.72° (at 10Hz).

- **Safety:** Class 1 Laser (Eye Safe).

## 3. Data Interface & Protocol

The C1 connects via a standard USB-Serial adapter (CP2102) included in the box.

### 3.1 The "Scan" Packet

The device outputs a continuous stream of polar coordinates.

- **Format:** `[Quality, Angle, Distance]`

  - `Quality`: Signal strength (0-255). Helps filter out dust/ghosts.

  - `Angle`: 0° to 360°.

  - `Distance`: Millimeters.

### 3.2 Power Requirements

- **Voltage:** 5V DC (Powered directly via USB).

- **Current:** \~200mA (Very efficient).

## 4. ROS 2 Integration (`sllidar_ros2`)

Slamtec provides an official, well-maintained ROS 2 driver.

### 4.1 Installation

We do not write the driver. We compile the official package in our `deploy_k9.sh` script.

```
sudo apt install ros-jazzy-sllidar-ros2

```

### 4.2 Topics & Messages

<table style="min-width: 75px;">
<colgroup><col style="min-width: 25px;"><col style="min-width: 25px;"><col style="min-width: 25px;"></colgroup><tbody><tr><td colspan="1" rowspan="1"><p><strong>ROS 2 Topic</strong></p></td><td colspan="1" rowspan="1"><p><strong>Message Type</strong></p></td><td colspan="1" rowspan="1"><p><strong>Description</strong></p></td></tr><tr><td colspan="1" rowspan="1"><p><code>/scan</code></p></td><td colspan="1" rowspan="1"><p><code>sensor_msgs/LaserScan</code></p></td><td colspan="1" rowspan="1"><p>The raw 2D slice of the world. Used by <code>Nav2</code> and <code>SLAM Toolbox</code>.</p></td></tr><tr><td colspan="1" rowspan="1"><p><code>/rpms</code></p></td><td colspan="1" rowspan="1"><p><code>std_msgs/UInt16</code></p></td><td colspan="1" rowspan="1"><p>Motor speed telemetry.</p></td></tr></tbody>
</table>

### 4.3 Configuration (`sllidar_node`)

We must set specific parameters in our launch file to match the C1.

```
channel_type: serial
serial_port: /dev/ttyUSB0  # (Or specific by-id path)
serial_baudrate: 460800    # C1 specific high-speed baud
frame_id: laser_frame
inverted: false
angle_compensate: true
scan_mode: Standard

```

## 5. Integration Strategy

### 5.1 Mechanical Mounting

- **Location:** **Top Rear Spine**.

- **Clearance:** It must be the highest point on the back to see over the "shoulders" of the robot.

- **Blind Spots:** The robot's own head (OAK-D) will create a small blind spot in the front. This is acceptable because the OAK-D covers that area with depth vision.

### 5.2 Interference Management

- **LIDAR vs. Vision:** The C1 uses infrared light (905nm). It operates on a different frequency than the OAK-D's ToF/Stereo sensors, so **no interference** is expected.

## 6. Summary for Engineers

The RPLIDAR C1 is the **"Localization Anchor."**

- **Input:** Laser pulses.

- **Output:** Precise distance to walls.

- **Usage:** It stops the map from drifting. While Odometry (Motor encoders) drifts by meters over time, the LIDAR snaps the robot back to the correct inch by matching the wall geometry.

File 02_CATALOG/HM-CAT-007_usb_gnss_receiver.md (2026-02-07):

---
ID: HM-CAT-007
Status: ACTIVE
Source: github.com/BigRigVibeCoder/HiveMind
---

# Component Specification: USB GNSS Receiver (The "Easy Button")

Role: Outdoor Global Localization

Hardware: VFAN USB GPS (UBX-G7020KT Chipset)

Interface: USB 2.0 (Virtual Serial Port)

Status: APPROVED

## 1. Hardware Overview

This unit is a "G-Mouse" style receiver. It encapsulates the antenna and the U-Blox 7 chipset into a single waterproof magnetic puck.

### 1.1 Specifications

- **Chipset:** UBX-G7020KT (U-Blox 7 Series).

- **Constellations:** GPS, GLONASS, QZSS, SBAS (56-Channel).

- **Protocol:** NMEA 0183 (Standard ASCII text).

- **Update Rate:** 1Hz - 10Hz (Default is usually 1Hz).

- **Accuracy:** \~2.5m (Standard Precision).

- **Mounting:** Magnetic Base.

- **Cable:** 2 Meters (6.5 ft).

## 2. Coordinate Systems (State-of-the-Art Standard)

The "Best-in-Class" Standard: WGS84 Decimal Degrees

Modern robotics pipelines (ROS 2, PX4, AutoWare) utilize WGS84 Latitude/Longitude natively.

- **Why it is the best:**

  - **Native Compatibility:** GPS satellites, Google Maps, and OpenStreetMap all speak this language. No conversion errors.

  - **Zero Friction:** The ROS standard message `sensor_msgs/NavSatFix` expects Lat/Long. Using this directly allows you to plug into tools like **Foxglove Studio** or **MapViz** instantly without writing custom adapters.

  - **Precision:** We use **Decimal Degrees** to 7+ decimal places (e.g., `34.052235, -118.243683`). This provides sub-meter resolution without the complexity of grid zones.

The Integration Strategy:

Instead of reading text coordinates (Old School), the SOTA approach is Visual Telemetry.

- **Robot:** Publishes Lat/Long.

- **Mission Control (Foxglove):** Automatically places a 3D robot icon on a streaming Satellite Map tile. You don't read coordinates; you look at the map.

## 3. Python Interfacing (Direct NMEA)

To use this directly in Python (bypassing ROS for testing), we read the raw NMEA stream. We strip away the MGRS conversion to reduce dependencies and latency.

### 3.1 Prerequisites

```
pip install pyserial pynmea2

```

### 3.2 The Parsing Script (`gps_reader.py`)

```
import serial
import pynmea2

# Configuration
PORT = "/dev/ttyACM0"  # or /dev/ttyUSB0
BAUD = 9600

def read_gps():
    try:
        with serial.Serial(PORT, BAUD, timeout=1) as ser:
            print(f"📡 Connected to GPS on {PORT} - Listening for Satellites...")
            while True:
                line = ser.readline().decode('ascii', errors='replace')
                
                # Filter for GNGGA or GPGGA (Global Positioning System Fix Data)
                if "GGA" in line:
                    try:
                        msg = pynmea2.parse(line)
                        lat = msg.latitude
                        lon = msg.longitude
                        sats = msg.num_sats
                        
                        # Output High-Precision Decimal Degrees
                        print(f"📍 Location: {lat:.6f}, {lon:.6f} | Satellites: {sats}")
                        
                    except pynmea2.ParseError:
                        continue
    except Exception as e:
        print(f"❌ Error: {e}")

if __name__ == "__main__":
    read_gps()

```

## 4. ROS 2 Integration

We use the standard NMEA driver. ROS will publish Lat/Long. We can add a custom node later to publish a secondary `/gps/mgrs` topic if needed for other systems.

### 4.1 Installation

```
sudo apt install ros-jazzy-nmea-navsat-driver

```

### 4.2 Launching the Node

Add this to your `system.launch.py`:

```
Node(
    package='nmea_navsat_driver',
    executable='nmea_serial_driver',
    name='gps_driver',
    parameters=[{
        'port': '/dev/ttyACM0',
        'baud': 9600,
        'frame_id': 'gps_link',
        'use_gnss_time': False,
        'time_ref_source': 'gps'
    }]
)

```

### 4.3 Output Data

- **Topic:** `/fix`

- **Message:** `sensor_msgs/NavSatFix` (Latitude, Longitude, Altitude).

## 5. Engineering Verdict: APPROVED

This component works seamlessly with Linux. The transition to MGRS is handled easily in software, giving you the military-grade readout you prefer without complicating the robot's internal math.

**Amazon Search Term:** `VFAN USB GPS Receiver` or `UBX-G7020KT USB GPS`.

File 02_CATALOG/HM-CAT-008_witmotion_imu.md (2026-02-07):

---
ID: HM-CAT-008
Status: ACTIVE
Source: github.com/BigRigVibeCoder/HiveMind
---

# Inertial Measurement Unit (IMU) - WitMotion WT901SDCL

**Role:** Proprioception & Balance (The Inner Ear)

**Hardware:** WitMotion WT901SDCL (USB-C Version)

**Interface:** USB 2.0 (Virtual Serial / TTL)

## 1. Hardware Overview

The WT901SDCL is a high-performance Attitude and Heading Reference System (AHRS). Unlike raw sensor chips, it contains an internal **Cortex-M4 Core** running a high-speed Kalman Filter to fuse raw data into stable orientation data on-device before sending it to the host.

### 1.1 Core Specifications

- **Sensors:** 9-Axis (3-axis Gyroscope, 3-axis Accelerometer, 3-axis Magnetometer).

- **Processor:** Internal Cortex-M4 (Running Dynamic Kalman Fusion).

- **Output Frequency:** Default 10Hz, Configurable up to **200Hz** (Recommended for K9) or 1000Hz.

- **Baud Rate:** Supports 115200 (Default) up to 921600.

- **Casing:** CNC Aluminum (Shields against RF interference from motors).

## 2. The Output Schema (Data Structure)

The device outputs data in two formats: **Raw Hexadecimal Packets** (at the serial level) which are converted into **ROS 2 Messages**.

### 2.1 The Serial Protocol (Raw Byte Stream)

If you inspect the raw USB data (`cat /dev/ttyUSB0`), you will see a stream of 11-byte packets starting with the header `0x55`.

| Header | Flag | Data Payload (8 Bytes) | Checksum | Meaning |
| --- | --- | --- | --- | --- |
| `0x55` | `0x51` | `axL axH ayL ayH azL azH TL TH` | `Sum` | **Acceleration** (g) & Temp |
| `0x55` | `0x52` | `wxL wxH wyL wyH wzL wzH TL TH` | `Sum` | **Angular Velocity** (deg/s) |
| `0x55` | `0x53` | `RolL RolH PitL PitH YawL YawH TL TH` | `Sum` | **Euler Angles** (Roll/Pitch/Yaw) |
| `0x55` | `0x54` | `HxL HxH HyL HyH HzL HzH TL TH` | `Sum` | **Magnetometer** (uT) |
| `0x55` | `0x59` | `Q0L Q0H Q1L Q1H Q2L Q2H Q3L Q3H` | `Sum` | **Quaternion** (Orientation) |

**Key Takeaway:** The "Angle" packet (`0x53`) and "Quaternion" packet (`0x59`) are the most valuable. They represent the *solved* math from the internal Kalman filter.

### 2.2 The ROS 2 Topic Schema (`sensor_msgs/Imu`)

The driver converts the raw hex into standard ROS 2 topics.

**Topic:** `/imu/data`\
**Message Type:** `sensor_msgs/msg/Imu`

```
header:
  stamp: {sec: 164000, nanosec: 500}
  frame_id: "imu_link"
orientation:             # Fused Data (From 0x59 Packet)
  x: 0.001
  y: 0.045
  z: -0.002
  w: 0.999
angular_velocity:        # Raw Gyro (From 0x52 Packet)
  x: 0.01
  y: -0.05
  z: 0.00
linear_acceleration:     # Raw Accel (From 0x51 Packet)
  x: 0.12
  y: 0.05
  z: 9.81 (Gravity)

```

**Topic:** `/imu/mag` (Optional)\
**Message Type:** `sensor_msgs/msg/MagneticField`

- Contains the raw X/Y/Z magnetic field data (From `0x54` Packet).

## 3. Integration Strategy

### 3.1 Physical Mounting (Critical)

- **Location:** Center of Mass (Middle of Bottom Plate).

- **Orientation:** \* **Label Up:** Z-axis points to sky.

  - **USB Port Back:** Ensure X-Axis arrow points to Robot Forward.

- **Fastening:** M2.5 or M3 screws + Loctite. Vibration damping is handled internally by the algorithm, but rigid mounting is preferred to prevent "sensor lag."

### 3.2 Software Setup (Ubuntu)

Because it uses a standard CH340 or CP2102 USB chip, Linux recognizes it instantly.

```
ls /dev/ttyUSB*
# Output: /dev/ttyUSB0 (or USB1)

```

## 4. ROS 2 Integration

### 4.1 Driver Installation

We use the standard driver which handles the hex parsing automatically.

```
sudo apt install ros-jazzy-witmotion-ros

```

### 4.2 Configuration Parameters

Set these in `imu_params.yaml`:

```
witmotion_imu:
  ros__parameters:
    port: "/dev/ttyUSB0"
    baud_rate: 115200   # Must match hardware setting
    poll_rate: 200      # 200Hz is ideal for walking robots
    frame_id: "imu_link"
    use_native_orientation: true # Use the internal Kalman filter (Better/Faster)

```

### 4.3 Calibration Procedure

**Do this ONCE before installing on the robot.**

1. Plug into Windows PC using WitMotion software.

2. Perform **Accelerometer Calibration** (Place flat, wait 3 sec).

3. Perform **Magnetic Calibration** (Rotate sensor in all 3 axes like a figure-8).

4. **Save to Flash.** The calibration is now stored on the device hardware.

## 5. Engineering Verdict

The **WT901SDCL** provides a pre-solved orientation vector. By subscribing to `/imu/data`, the Balance Controller knows exactly how much the robot is tilting without doing any trigonometry on the Main CPU.

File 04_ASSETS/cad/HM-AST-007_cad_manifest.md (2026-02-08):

---
ID: HM-AST-007
Status: ACTIVE
Role: CAD Assembly Manifest
Date: 2026-02-08
Generator: 06_ENGINEERING/00_TOOLS/generate_chassis.py (v6)
Parts: 06_ENGINEERING/00_TOOLS/generate_parts.py
Output: 04_ASSETS/cad/
Linked: HM-CAT-001, HM-CAT-010, HM-CAT-012, HM-CAT-013, HM-CAT-014, HM-CAT-015
---

# CAD Assembly Manifest — Nomad-T Phase 1

> [!NOTE]
> **This document lives alongside the STEP files** and serves as their table of contents, traceability map, and regeneration guide.

## 1. Quick Start

### View Any Model
Drag any `.step` file into:
- **[3dviewer.net](https://3dviewer.net)** — Zero install, browser-based
- **FreeCAD** — `File → Import → STEP`
- **Fusion 360** — `Insert → Upload`
- **SolidWorks** — `File → Open → STEP`

### Regenerate
```bash
# Full assembly (59 parts)
python3 06_ENGINEERING/00_TOOLS/generate_chassis.py

# Individual manufacturing parts
python3 06_ENGINEERING/00_TOOLS/generate_parts.py
```
**Requires:** Python 3.12 + CadQuery (`~/.local/lib/python3.12/site-packages/cadquery`)

---

## 2. File Inventory

| File | Size | Description |
|:---|:---|:---|
| `HM-AST-006_nomad_t_chassis.step` | 393 KB | Full robot assembly (59 named parts) |
| `parts/NMT-MP-001_motor_plate.step` | 146 KB | Motor plate — **send to waterjet/laser shop** |
| `parts/NMT-TD-001_thermal_deck.step` | 173 KB | Thermal deck plate — CNC or waterjet |
| `parts/NMT-FR-001_frame_assembly.step` | 73 KB | Frame rails + crossbeams — cut-list verification |

---

## 3. Assembly Parts Map (59 Parts)

### Structure (HM-CAT-013)
| STEP Name | Description |
|:---|:---|
| `rail_L`, `rail_R` | 700mm 2040 V-Slot side rails |
| `xbeam_1` – `xbeam_4` | 240mm 2040 crossbeams |
| `shear_L`, `shear_R` | 3mm DiBond side panels (700×120mm) |

### Drivetrain (HM-CAT-010 / HM-CAT-015)
| STEP Name | Description |
|:---|:---|
| `g30_hub_FL/FR/RL/RR_tire` | 250mm 10" pneumatic tires |
| `g30_hub_FL/FR/RL/RR_motor` | 140mm motor body (inside tire) |
| `g30_hub_FL/FR/RL/RR_axle` | 12mm Double-D axle stub |
| `motor_plate_FL/FR/RL/RR` | NMT-MP-001 6mm Al plates with axle bore |

### Electronics (HM-CAT-012 / HM-CAT-014)
| STEP Name | Description |
|:---|:---|
| `apache_3800` + `case_handle` | Protective case + handle |
| `thermal_deck` | 6mm Al unified thermal plate |
| `bobbin_FL/FR/RL/RR` | M5 vibration isolation bobbins |
| `battery_10s3p` + `battery_xt90` | 36V pack + XT90-S connector |
| `vesc_FL/FR/RL/RR` | Flipsky 75100 motor controllers |
| `brake_resistor` | 200W 8Ω regen brake |
| `dcdc_meanwell` | DDR-60L-15 (36V→17V) |
| `arduino_nano` | Watchdog heartbeat monitor |
| `distribution_bus` | Power distribution block |
| `main_contactor` | HV switching contactor |

### Sensors
| STEP Name | Description |
|:---|:---|
| `rplidar_c1` + `lidar_mast` | RPLiDAR C1 on mast (>300mm) |
| `oakd_lite` + 3× `oakd_lens_*` | OAK-D Lite with lens bumps |
| `ir_FL/FR/FC/RC` | Sharp IR range finders |
| `imu_wt901` | WitMotion WT901SDCL 9-axis AHRS |

### Safety & UI (CDR-6, CDR-12)
| STEP Name | Description |
|:---|:---|
| `estop_button` | Red mushroom E-Stop (rear) |
| `led_green/yellow/red` | Status LEDs (rear panel) |
| `charge_port` | Weipu SP17 charging connector |

---

## 4. Individual Parts Detail

### NMT-MP-001 Motor Plate (146 KB)
**The linchpin of the design.** Manufacturing-ready with:
- Double-D axle slot (12mm OD, 10mm flats)
- 6× M5 clearance holes (4 primary + 2 edge)
- 2mm chamfered edges
- Material: 6061-T6, 6mm thick
- **Process:** Waterjet or laser cut

### NMT-TD-001 Thermal Deck (173 KB)
- 4× corner M5 mounting holes
- 16× M3.5 VESC mount holes (4 per VESC × 4 VESCs)
- 4× M3 Odroid standoff holes
- 4× M3 copper pedestal contact holes
- 2× 16mm wire gland pass-through holes
- 1.5mm filleted top edges
- **Process:** CNC or waterjet

---

## 5. Coordinate System & Key Dimensions

| Axis | Direction | | Parameter | Value |
|:---|:---|:---|:---|:---|
| **+X** | Forward | | Frame | 700 × 320mm |
| **+Y** | Left | | Wheelbase | 700mm |
| **+Z** | Up | | Track | 450mm |
| Origin | Rear axle, ground | | Wheel OD | 250mm |

---

## 6. Wiring Diagram

See [HM-DWG-002_wiring_visual.png](file:///home/bdavidriggins/Documents/Nomad-T/06_ENGINEERING/01_SCHEMATICS/HM-DWG-002_wiring_visual.png) for color-coded wiring diagram, and [HM-DWG-001](file:///home/bdavidriggins/Documents/Nomad-T/06_ENGINEERING/01_SCHEMATICS/HM-DWG-001_wiring_harness.md) for pin-to-pin netlist.

For formal, editable schematics with DRC: use **[KiCad](https://www.kicad.org/)** (free, open-source EDA).

---

## 7. Version History

| Version | Date | Changes |
|:---|:---|:---|
| **v6** | 2026-02-08 | 59-part assembly, individual part files, wiring diagram |
| v5 | 2026-02-08 | 33-part assembly, first correct design |
| v4 | 2026-02-07 | *Obsolete:* suspension, diffs, belt drive |

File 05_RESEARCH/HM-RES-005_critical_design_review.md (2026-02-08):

---
ID: HM-RES-005
Status: ACTIVE
Date: 2026-02-07
Role: Independent Critical Design Review
Architecture: Nomad-T G30 Standard (Rev 3.2)
Linked: HM-RES-003, HM-RES-004, HM-CAT-016
Reviewer: Engineering Partner (adversarial review)
---

# Critical Design Review — Nomad-T

> [!CAUTION]
> **This is an adversarial review.** Everything below challenges decisions that were previously marked "✅ ANSWERED." Some of these are serious. None are personal — they exist because a robot that falls apart in the field teaches nothing.

---

## CDR-1: Skid-Steer Bearing Abuse (RQ-1.1, 1.2) 🟡 CONFIRMED

**The problem nobody talked about:**

The G30 motor bearings are designed for a scooter rolling forward. We're using them in a skid-steer robot that **drags wheels sideways during every turn.** The consultant analyzed cantilever bending (radial load) — correct. But skid-steer generates **lateral scrubbing forces** that the G30 bearings were never designed for.

- During a zero-radius turn, each wheel is dragged perpendicular to its rolling axis.
- Scrub force per wheel: ~6 kg × 9.81 × μ ≈ **35N laterally.**
- This lateral force is applied at the tire contact patch, 55mm from the nearest bearing.
- **This is a thrust load on a radial bearing.** Deep-groove ball bearings can handle some axial load (~50% of radial rating), but repeated lateral impacts (curbs, rocks, ruts) during skid turns will accelerate bearing wear.

**Consultant response (CONFIRMED):** The delivery robot community (using similar hub motors in 4WD skid-steer) has identified the weak points: **internal snap rings and bearing seats** fail first under sustained grit/impact duty cycles. No formal whitepaper, but field-validated.

**Required actions:**

1. **Seal upgrade:** Verify the G30 uses high-quality **2RS seals** (rubber contact seals). If factory seals are generic, upgrade to **SKF or NSK equivalent** to keep grit out of the races. This is the #1 life extension.
2. **Maintenance schedule:** Check for **"wheel click" (axial play)** every **50 km of operation.** Test: grab the tire and wiggle side-to-side. Any detectable play = bearings approaching fatigue limit. Budget ~$20 for replacement bearing set.
3. **Spares:** Procure one spare set of G30 bearings (likely 6001-2RS, 12×28×8mm) during Phase 0. **Verify exact bearing model after disassembling first motor.**

---

## CDR-2: Fatigue on the Cantilever Axle (RQ-1.2) 🟡 CONFIRMED

The consultant's Factor of Safety >20 is for **static** loading. The robot will hit curbs, roots, and rocks. Each impact is a shock load on a cantilevered 12mm axle, and every shock cycle counts toward fatigue.

- Steel fatigue endurance limit is ~40-50% of yield strength. The G30 axle is likely low-carbon steel (~250 MPa yield), so fatigue limit ≈ 125 MPa.
- At 3.5 Nm static, the bending stress is ~4.3 MPa. FoS >20 for static. But a 5G shock (hitting a curb at speed) → 17.5 Nm → 21.5 MPa. Still safe, but **the D-flat slot in the mounting plate is a stress concentrator.** Sharp corners in the D-flat cutout multiply local stress by 2-3×.

**Consultant response (CONFIRMED):** Fatigue is the "silent killer" of robotic chassis in cantilever designs. Every curb strike is a high-amplitude stress cycle.

**Required actions:**

1. **CAD rule — fillet radii:** When drawing the D-shape axle hole, **do NOT let the flat lines meet the circle at a sharp point.** Use the Fillet tool to round all four intersection points to **≥ 2mm radius.** This is a SendCutSend requirement.

2. **Material upgrade (consultant recommendation):**

   | Material | Pros | Cons | Recommendation |
   |:---|:---|:---|:---|
   | 6061-T6 Aluminum (6mm) | Light, easy to machine | Lower fatigue strength, corrodes in mud | Original spec — adequate for Phase 1 |
   | **304 Stainless Steel (4mm)** | **Rust-proof in mud/snow, higher fatigue limit** | Heavier, harder to machine | **Recommended for field duty** |
   | AR400/500 Steel (4mm) | Extreme impact hardness, "battle-hardened" | Difficult to machine, heavy, rusts | Overkill unless extreme impacts expected |

   > [!TIP]
   > **SendCutSend offers both 304 SS and AR400 as standard materials.** If upgrading from 6mm aluminum to 4mm 304 SS, the plate rigidity is similar (steel E-modulus is 3× aluminum, offsetting the thinner gauge) and it won't corrode in wet field conditions.

---

## CDR-3: No Vibration Isolation for Electronics (RQ-2.1, 5.1) 🔴 CONFIRMED — CRITICAL

**Consultant verdict: Hard-mounting the Apache case is REJECTED.**

A skid-steer robot on gravel generates sustained **high-frequency vibration** (hundreds of Hz) from tire treads and scrubbing. A rigid monocoque transmits this with zero damping directly into the electronics.

### Failure Modes (Consultant Analysis):

1. **Connector fretting (RAM/SSD):** High-frequency micro-motion wears through gold contact plating → oxidation → intermittent connections. Result: random reboots and data corruption in the field.

2. **Nylon standoff creep (THERMAL CATASTROPHE):** This is the killer.
   - Nylon has high CTE and creeps under constant load + heat.
   - Vibration acts as an impact driver — it **will** back nylon screws out.
   - If the copper pedestal shifts 1mm, it slides off the 10×10mm CPU die.
   - **Thermal resistance → infinity. CPU fries instantly.**

### The Fix: Vibration Isolation Bobbins

Decouple the "sprung mass" (Apache case + electronics) from the "unsprung mass" (chassis + motors).

| Bobbin Spec | Value |
|:---|:---|
| Type | Cylindrical male-male studs (one end into T-nut, other through case floor) |
| Thread | **M5 or M6** |
| Dimensions | ~15–20mm diameter, 15–20mm height |
| Durometer | **Shore 40A–50A** (do NOT exceed 60A — too stiff for high-freq) |
| Material | Neoprene or Silicone |
| Fastening | **Nyloc nuts** inside case (NO Loctite near ABS — causes stress cracking) |
| Frame side | Split washer on T-nut side |
| Quantity | **4× minimum** |
| Cost | **~$8 total** |

> [!CAUTION]
> **NO LOCTITE NEAR PLASTIC.** Liquid threadlocker (Loctite Blue 243) attacks ABS/polycarbonate (stress cracking) and degrades rubber. Use Nyloc nuts only.

### Environmental Sealing (Three-Way Consensus) ✅

Drilling bobbin holes voids IP65. The following sealing protocol restores it:

1. **Outside (between bobbin flange and case floor):** **M5 bonded sealing washer** (rubber-backed metal washer) — compresses into a gasket under the bobbin stud head.
2. **Inside (before fender washer and Nyloc nut):** Bead of **marine-grade RTV silicone** around the stud hole.
3. Result: Each penetration is double-sealed (mechanical + chemical).

### Wire Routing Across Isolation Boundary (Three-Way Consensus) ✅

Stiff wires bridging the bobbin gap short-circuit the vibration isolation.

**Assembly rule (mandatory):**
1. Secure wire bundle tightly to 2040 frame with P-clip **before** the case.
2. Leave a **50mm flexible service loop** (S-shape or C-shape) that can flex freely.
3. Secure wire bundle tightly **inside** the Apache case immediately after entry.
4. Use high-strand-count **silicone-jacketed wire** for motor phase leads. **PVC-jacketed wire is not acceptable.**

### CDR-3 Status: ✅ RESOLVED

All three parties agree. BOM additions: 4× M5 Shore 40A bobbins ($8), 4× bonded sealing washers ($2), RTV silicone ($5), Nyloc nuts + fender washers ($2). **Total: ~$17.**

---

## CDR-4: Thermal Deck CTE Mismatch & Paste Pump-Out (RQ-5.1) 🟡 CONFIRMED — RESOLVED

**Consultant verdict: Thermal interface strategy revised. Hybrid TIM approach required.**

Over a 60°C operating cycle, the aluminum beneath the 40mm copper block expands ~15 µm more than the copper. This creates a pumping action that migrates thermal paste out of the gap over hundreds of cycles → dry spots → thermal failure.

### The Fix: Hybrid TIM Strategy (Consultant + Engineering Partner Consensus)

| Interface | Location | Material | Spec | Why |
|:---|:---|:---|:---|:---|
| **A** | Copper → Aluminum plate | **Thermal Pad** | 0.5mm, **≥ 6.0 W/m·K** | Absorbs 15µm CTE shear without migration |
| **B** | Copper → CPU die | **Thermal Paste** | **≥ 8.0 W/m·K** | Minimum bond line for fragile bare die |

**Recommended products:**
- **Interface A (pad):** Fujipoly Sarcon XR-series or Laird Tflex HP (~$8 for a sheet)
- **Interface B (paste):** Thermal Grizzly Kryonaut or Arctic MX-6 (~$8 tube)

> [!IMPORTANT]
> **Bolt type clarification — two different bolt sets, two different rules:**
> - **Cu-to-Al plate bolts:** Use **metal bolts** (M3 or M4 steel), torqued to pad manufacturer's recommended pressure for full wet-out. Metal is fine here — the pad absorbs CTE differential.
> - **Cu-to-CPU die clamp (through Odroid board):** Use **nylon standoffs** at **0.3–0.5 Nm max.** The die is 10×10mm exposed silicon — metal bolts over-torqued here will crack it. These are NOT the same bolts.

### CDR-4 Status: ✅ RESOLVED

BOM additions: 1× thermal pad sheet ($8), 1× thermal paste tube ($8). **Total: ~$16.**

---

## CDR-5: Regen Braking with Full Battery = Loss of Control (RQ-3.4) 🔴 CONFIRMED — CRITICAL SAFETY

> [!CAUTION]
> **My original software-only fix was WRONG.** Setting `battery_cut_end = 42V` saves the battery but **kills all braking force.** On a hill, the robot free-wheels uncontrollably. The consultant correctly identified this as a safety-critical failure.

**Consultant verdict: The Flipsky 75100 does NOT protect the battery from regen overvoltage.** Its protections are designed to save the VESC (cuts at ~70V), not the cells. Software voltage limits cause instant loss of braking torque.

### The Failure Sequence (Software-Only):

1. Robot descends steep hill with 100% charged battery (42V).
2. Driver brakes → VESCs regen → bus voltage pushes past 42V.
3. VESC firmware hits `battery_cut_end` → **stops regenerating instantly.**
4. **ZERO braking force.** Robot free-wheels downhill.

### The Fix: Hardware Brake Shunt (Rheostatic Braking)

A power resistor + switch dumps excess regen energy as heat, allowing the VESC to maintain braking torque without over-volting the battery.

| Component | Spec | Cost |
|:---|:---|:---|
| Power Resistor | **200W, 8Ω chassis-mount wirewound** (100W insufficient for sustained braking — see math below) | ~$15 |
| DC Solid State Relay | **60V DC, ≥25A continuous** (Fotek SSR-25 DD or equivalent) | ~$15 |
| Wiring | Resistor + SSR in series, across battery P+ and P- | — |
| Control | VESC Master GPIO pin → SSR control input | — |

**VESC Configuration (VESC Tool):**
1. App Settings → Nrf/UART/Brake → External Brake Resistor
2. Select GPIO pin connected to SSR control
3. Set brake threshold: **43.0V** (just above full charge)
4. When bus voltage hits 43V during braking, VESC fires GPIO → SSR activates → current dumps into resistor → voltage drops → braking force maintained.

**Mounting:** Resistor bolted to aluminum frame rail (NOT near the Apache case — resistor surface exceeds 100°C). Frame acts as heatsink.

### Resistor Sizing Validation (Three-Way Consensus) ✅

Peak dump power at 43V across 8Ω: P = V²/R = 43²/8 = **231W.** A 100W resistor handles 5-second bursts (wirewound thermal mass), but a sustained 30-second downhill brake at full charge will burn it out — and an open-circuit resistor puts you back to square one (no brakes or over-volted battery). **200W provides adequate margin.**

**Thermal clearance (mandatory):** Resistor surface can exceed **250°C** under full load. Maintain **≥100mm clearance** from:
- Apache case (ABS softens >105°C)
- DiBond panels (PE core melts >120°C)
- Any wiring insulation

Bolt resistor to bare 2040 aluminum rail with **thermal paste** at the mounting pad. Frame acts as heatsink.

### CDR-5 Status: ✅ RESOLVED (Hardware fix required)

BOM additions: 1× 200W 8Ω wirewound resistor ($15), 1× 60V/25A DC SSR ($15), wiring + connectors ($5). **Total: ~$35.**

---

## CDR-6: No Hardware Watchdog / E-Stop Path (RQ-3.3, 4.1) 🔴 CONFIRMED — CRITICAL SAFETY

> [!CAUTION]
> **The current design is UNSAFE.** There is no positive method to disconnect high voltage during a software failure. A kernel panic, segfault, or frozen ROS node could result in a full-speed runaway robot. This is mandatory before any field operation.

**Consultant verdict:** No physical kill switch exists in the design. VESC CAN timeout is not sufficient — a crashing Odroid can spew garbage CAN data that resets the timeout, or hardware CAN buffers can re-transmit the last valid frame indefinitely ("zombie state"), locking the robot at its last speed until battery death or impact.

### The Fix: Hardware Safety Chain

The main contactor coil must pass through **two hardware safety devices in series.** If either link breaks, the contactor opens and all motor power is cut.

```
[+12V Source] → [E-Stop NC] → [Watchdog Relay NO] → [Contactor Coil +]
                                                      [Contactor Coil -] → [GND]
```

**Contactor engages ONLY IF:** (E-Stop is NOT pressed) **AND** (Watchdog is receiving heartbeat)

#### Link 1: Physical E-Stop (Kill Switch)

| Spec | Value |
|:---|:---|
| Type | **Industrial mushroom-head pushbutton** |
| Action | Push-to-lock, twist-to-reset |
| Rating | **IP65/IP67** (sealed against rain/mud) |
| Contacts | **NC (Normally Closed)** — in series with contactor coil supply |
| Cost | ~$8 |

#### Link 2: Hardware Watchdog Timer

| Spec | Value |
|:---|:---|
| MCU | **Arduino Nano** or ATtiny85 (~$3) |
| Relay | Small logic-level relay or MOSFET ($2) — controls contactor coil circuit |
| Heartbeat | Odroid must send a signal every ~100ms |
| Timeout | If no signal for **500ms**, watchdog drops relay → contactor opens |
| Cost | ~$8 total |

### 🔍 My Pushback: The Odroid Has No GPIO

The consultant's design says "toggle a GPIO pin." **The Odroid H4 Ultra does NOT have a GPIO header.** It's an x86 SBC, not a Raspberry Pi. Its interfaces are:
- 4× USB 3.0, 1× USB 2.0
- 2× Ethernet (2.5GbE)
- HDMI, DisplayPort
- M.2 slots
- **No user-accessible GPIO pins**

**Fix: USB-serial heartbeat instead of GPIO.**

1. Connect the Arduino Nano to the Odroid via **USB cable** (the Nano appears as `/dev/ttyUSB0`).
2. The Odroid runs a lightweight daemon that writes a keep-alive byte (`0xA5`) to the serial port every 100ms. This is a 10-line Python script or systemd service.
3. The Arduino validates byte value and timing. If no valid byte for 500ms → kill the relay.
4. **Why this works:** If the Odroid kernel panics, the serial daemon dies, no bytes are sent, the watchdog fires. If USB hardware hangs, same result — no bytes flow, watchdog fires.

> [!IMPORTANT]
> The USB-serial approach is actually **more reliable** than GPIO for watchdog purposes. A GPIO pin can be held high by a crashed process if the pin was set before the crash. A serial byte stream requires the daemon to be actively running — if ANY part of the software stack dies (kernel, Python runtime, systemd), the stream stops.

### E-Stop Mounting Location (Three-Way Consensus) ✅

**Location: DiBond side panel, top edge (left or right side).**

- **Accessibility:** In a runaway, the operator runs alongside and hits the button from standing — no reaching down toward wheels or leaning over the chassis.
- **Visibility:** Most prominent location on the robot.
- **Rigidity:** DiBond is rigid. Mounting to the vibration-isolated Apache case makes it a "moving target" on rough terrain.
- **Wiring:** Through M22 waterproof panel mount. Wire runs inside frame rail channel.

### CDR-6 Status: ✅ RESOLVED (Hardware safety chain required)

BOM additions: 1× IP65 mushroom e-stop ($8), 1× Arduino Nano ($3), 1× 5V relay module ($3), 1× USB cable ($2), wiring ($2). **Total: ~$18.**

---

## CDR-7: CAN Bus Single Point of Failure (RQ-3.2, 4.1) 🟡 CONFIRMED — RESOLVED

All 4 VESCs on a single CAN bus daisy chain is a single point of failure. If one transceiver fails shorted, the entire bus dies.

### The Fix: Proper CAN Hygiene (Consultant + Engineering Partner Consensus)

**For Phase 1, accept single CAN bus but implement it correctly:**

| Requirement | Spec |
|:---|:---|
| Topology | **Daisy-chain only** — no star, no stubs |
| Wiring | **Shielded Twisted Pair (STP)** — NOT loose wires |
| Termination | **120Ω resistor at each physical end** of the bus (first VESC and last VESC) |
| Bus order | Odroid CAN adapter → VESC1 → VESC2 → VESC3 → VESC4 |
| Shield grounding | Shield grounded at **one end only** (Odroid side) to prevent ground loops |

**Phase 2 upgrade path:** Split into dual CAN buses (left pair + right pair) using two USB-CAN adapters. If one bus dies, opposite-side motors still function for a limp-home mode.

### CDR-7 Status: ✅ RESOLVED

BOM additions: STP cable (~$5), 2× 120Ω termination resistors ($0.20). **Total: ~$5.**

---

## CDR-8: Mean Well DC-DC Voltage Mismatch (RQ-3.4) 🔴 CONFIRMED — BOM CHANGE REQUIRED

**Consultant verdict: The SD-50B-24 is REJECTED.** Minimum trim output is 21V — exceeds Odroid's 20V max input. Would destroy the board.

**Consultant solution: Switch to SD-50B-12 and trim UP to 16V.**

| Spec | SD-50B-24 ❌ REJECTED | SD-50B-12 ✅ PROPOSED |
|:---|:---|:---|
| Output | 24V (trim 21–28V) | 12V (trim **11–16V**) |
| Target | 19V — **unreachable** | **16V — at top of trim range** |
| Odroid safe? | ❌ 21V > 20V max | ✅ 16V in 14–20V range |
| Power at target | 50W at 24V = 2.08A | 50W at 16V = **3.125A** |
| Odroid max draw | 34W / 16V = 2.125A | **Within 3.125A limit** ✅ |

**Why 16V is ideal:** Sits in the middle of the Odroid's 14–20V range, provides 2V buffer above 14V minimum against sag during heavy CPU+GPU loads.

**Assembly rule:** Before connecting Odroid, power up SD-50B-12 and use multimeter + screwdriver to adjust V_ADJ trim pot clockwise to **16.0V.** Verify with multimeter under no-load. **Never connect without verifying.**

### 🔴 My Pushback: Input Voltage Range Mismatch

**Neither I nor the consultant caught this initially.** The SD-50B-12 input range is **19V – 36V.** Our 10S battery hits **42V at full charge** — 6V over the max input. The SD-50C-12 (36–72V) drops out below 36V, losing the Odroid with 20%+ battery remaining. **Neither B nor C covers 30V–42V.**

### ✅ FINAL SOLUTION: Mean Well DDR-60L-15 (Three-Way Consensus)

The consultant located the correct part family: **wide-input "4:1" industrial DIN-rail DC-DC converters.**

> [!WARNING]
> **Do NOT use cheap Amazon/AliExpress buck modules (XL4016, LTC3780).** They are electrically noisy (corrupts USB peripherals, sensors), have poor thermal management, and degrade under vibration. Do not power the robot's brain with hobby-grade electronics.

| Spec | DDR-60L-15 ✅ SELECTED |
|:---|:---|
| Input range | **18V – 75V DC** (covers 30V LVC to 42V full charge with massive headroom) |
| Output | 15V nominal, trim **13.5V – 18V** |
| Target output | **17.0V** (centered in Odroid 14–20V range, 3V buffer each side) |
| Power | **60W** (4A at 15V) — Odroid max 34W = **2.0A at 17V** ✅ |
| Form factor | Ultra-slim DIN rail mount |
| Mounting | 100mm segment of 35mm DIN rail on DiBond electronics panel |

**Assembly procedure:**
1. Mount 100mm DIN rail segment to DiBond panel (2× screws).
2. Clip DDR-60L-15 onto rail (better vibration resistance than old chassis-mount).
3. Power from battery **unloaded** (Odroid disconnected).
4. Adjust front-panel trim pot to **17.0V** — verify with multimeter.
5. Connect Odroid only after confirming 17.0V ± 0.5V.

### CDR-8 Status: ✅ RESOLVED (Third iteration)

| Iteration | Part | Result |
|:---|:---|:---|
| 1 | SD-50B-24 | ❌ Output min 21V > Odroid 20V max |
| 2 | SD-50B-12 | ❌ Input max 36V < battery 42V full |
| 3 | **DDR-60L-15** | ✅ **18–75V input, 15V out → trim to 17V** |

BOM change: Remove SD-50B-24, add **Mean Well DDR-60L-15** + 100mm DIN rail segment. Cost delta: ~$10 more than original.

---

## CDR-9: Mass Retention — Case + Battery (RQ-2.1) 🔴 CONFIRMED — CRITICAL SAFETY

Two heavy masses are unrestrained in the current design. In a 10G impact (hitting a wall at 4 m/s, ~40mm crush distance):

| Item | Mass | Force at 10G | Current Retention | Risk |
|:---|:---|:---|:---|:---|
| Apache 3800 case | 1.8 kg | **176N** | Bobbins (CDR-3) | ✅ Solved |
| **10S Li-Ion battery** | **~5 kg** | **490N** | **None** | 🔴 **Arc flash / fire** |

> [!WARNING]
> **The battery is a kinetic weapon deployed against your own robot.** If it shifts and a terminal contacts the aluminum frame → hundreds of amps short circuit → welds to frame → immediate thermal runaway (fire).

### Part A: Apache Case Retention ✅ CLOSED

CDR-3 vibration bobbins (4× M5 studs + Nyloc nuts) provide positive retention in X, Y, and Z. No additional work needed.

### Part B: Battery Retention (Three-Way Consensus)

#### 1. Battery Floor Plate (Consultant Addition — Critical)

**You cannot strap a battery directly across open 2040 rails.** The battery sags in the middle, and vibration causes sharp V-slot inner edges to saw through the PVC shrink wrap like an orbital sander.

| Spec | Value |
|:---|:---|
| Material | Scrap DiBond piece or 3mm aluminum plate |
| Mounting | Bolted to V-slots via T-nuts, bridging the two bottom rails |
| Padding | **3mm adhesive neoprene foam** on top surface (anti-slip + shock absorption) |

#### 2. Strap System

| Spec | Value |
|:---|:---|
| Quantity | **2× separate straps** |
| Width | 1 inch (25mm) nylon webbing |
| Buckles | **Metal cam buckles** (plastic buckles break under vibration) |
| Routing | Under the battery floor plate, over the top of the battery |
| Cost | ~$5 |

**Abrasion check:** File/deburr any sharp edges where straps pass through 2040 extrusion slots.

#### 3. Terminal Safety — "No Sparks" Rule (Consultant Override)

> [!CAUTION]
> **Kapton tape is insufficient** — it wears through and falls off under vibration. My original recommendation was wrong.

**Requirement:** The main battery power leads must terminate in a **fully shrouded, high-amperage connector:**
- **XT90-S Anti-Spark** (preferred — built-in pre-charge resistor prevents arc on plug-in)
- Anderson Powerpole PP75 (acceptable alternative)

**Rule:** No exposed conductive metal (ring terminals, spade connectors, bare bullet connectors) is permitted on the battery side of the connection. **Ever.**

### CDR-9 Status: ✅ RESOLVED

BOM additions: 1× DiBond/Al floor plate (scrap), 1× neoprene foam sheet ($3), 2× cam buckle straps ($5), XT90-S connectors ($4 pair). **Total: ~$12.**

---

## CDR-10: No Graceful Shutdown Path (RQ-4.1) 🟡 CONFIRMED — RESOLVED

**Hard-cutting power to an Ubuntu NVMe system is Russian Roulette with your data.** ext4 journal corruption will eventually brick the OS, requiring manual filesystem repair in the field (keyboard + monitor on a muddy robot).

### My Original Proposals — Both Rejected:

| Option | Verdict | Why |
|:---|:---|:---|
| Read voltage via VESC CAN bus | ❌ Rejected | Violates defense-in-depth — relies on ROS + CAN drivers staying alive to save themselves |
| Hardware ADC on Odroid | ❌ Rejected | Odroid H4 Ultra is x86 — **no analog input pins** |

### ✅ The Fix: Leverage the CDR-6 Arduino Watchdog (Consultant Solution)

The Arduino Nano from CDR-6 is already connected to the Odroid via USB serial and monitoring heartbeats. **Add battery voltage sensing to this existing hardware** — no new components needed beyond two resistors.

#### 1. Voltage Divider Circuit (add to Arduino Nano)

```
Battery (+) → [R1: 100kΩ] → Arduino A0 → [R2: 10kΩ] → Battery GND
```

- **Max measurable:** 5V × (100+10)/10 = **55V** (safe for 42V 10S pack)
- **Components:** 2× ¼W resistors ($0.20 total)

#### 2. Arduino Firmware Update

The watchdog sketch now does double duty:
- **Heartbeat watchdog** (CDR-6): Kill relay if no `0xA5` byte for 500ms
- **Voltage reporting** (CDR-10): Read A0, calculate real voltage, send `V:38.4\n` over serial every second

#### 3. Odroid Daemon Update

The existing Python watchdog daemon now also parses voltage telemetry:
- If voltage < **32.0V** (3.2V/cell) for **>5 consecutive seconds** → execute `shutdown -h now`
- This gives the OS ~60 seconds to halt cleanly before the BMS hard-cuts at ~30V (3.0V/cell)

> [!IMPORTANT]
> **Why this is superior to CAN bus monitoring:** The shutdown daemon is a 20-line Python script running as a systemd service, completely independent of ROS 2. If ROS crashes AND the battery is low, this daemon still runs and triggers a clean shutdown. Defense in depth.

### CDR-10 Status: ✅ RESOLVED

BOM additions: 2× resistors ($0.20). Firmware + software update only. **Total: ~$0.20.**

---

## CDR-11: Charging Port Design (missing entirely) 🟡 CONFIRMED — RESOLVED

Opening the sealed Apache case every charge cycle wears latches, breaks IP65, and exposes electronics to the environment. An external charge port is mandatory.

### My Original Proposal — Rejected:

I proposed an XT60 panel mount ($3). **The consultant correctly identified this creates a live 42V dead-short risk on the exterior of the robot.** Hobby connectors lack sealing caps, are easily fouled by mud, and have exposed pins.

### ✅ The Fix: Industrial IP68 Charge Connector + Fuse (Consultant Solution)

#### 1. Connector Specification

| Spec | Value |
|:---|:---|
| Part | **Weipu SP13 or SP17 series (2-pin)** mated pair |
| Rating | **IP68 when capped** — true waterproof, not just splash-resistant |
| Features | Threaded coupling (vibration-proof), shrouded contacts (short-proof), tethered cap |
| Mounting | Female panel-mount receptacle in Apache case side wall, with included rubber gasket |
| Cost | ~$12 per mated pair |

**The tethered cap MUST be installed whenever not charging.**

#### 2. Dedicated Charge Fuse (Consultant Addition — Critical)

> [!CAUTION]
> You cannot wire an external port directly to the battery. If someone (or debris) shorts the exposed pins, you get an arc flash from the full battery pack.

| Spec | Value |
|:---|:---|
| Fuse | **10A automotive blade fuse** in inline fuse holder |
| Location | On the positive line, **immediately inside the Apache case** between the Weipu connector and the BMS charge port |
| Purpose | If the external port is shorted, 10A fuse blows instantly — main battery and wiring remain protected |

#### 3. Wiring Path

```
External Weipu Port → [10A Fuse] → BMS Charge Terminals (C+/C-)
```

- Charge path **bypasses the main contactor** — allows charging while robot is powered off
- **Charging feedback:** Rely on the charger brick's LED indicator (Red = charging, Green = complete). Do NOT add displays or LEDs to the robot exterior — each penetration is another potential leak path

### CDR-11 Status: ✅ RESOLVED

BOM additions: 1× Weipu SP17 2-pin pair ($12), 1× 10A inline fuse holder ($3), 10A blade fuses ($1). **Total: ~$16.**

---

## CDR-12: No Status Indicators (missing entirely) 🟢

## CDR-12: No Status Indicators (missing entirely) 🟢 CONFIRMED — RESOLVED

The Odroid is headless. WiFi is the only interface. If WiFi drops, you're completely blind.

### My Original Proposal — Rejected:

I proposed NeoPixels driven by the Odroid. **The consultant caught me forgetting my own CDR-6 finding:**
1. **No GPIO:** The Odroid H4 Ultra has no GPIO header to drive NeoPixels.
2. **Software-dependent:** NeoPixels need precise timing. A kernel panic during boot = no LEDs = zero information.

### ✅ The Fix: Industrial "Traffic Light" (Consultant Solution)

Three separate panel-mount LED indicators driven by existing hardware — no software dependency for basic health.

| LED | Color | Driven By | Logic | Meaning |
|:---|:---|:---|:---|:---|
| **Green** | 🟢 | Arduino Nano (USB command from Odroid) | ON only when Odroid daemon confirms all critical ROS nodes are running. Odroid crash → heartbeat stops → Arduino kills green. | **Software stack healthy** |
| **Yellow** | 🟡 | Arduino Nano (**autonomous**) | Blink if battery < 34V. Solid if < 32V. Uses CDR-10 voltage divider data. Works even if Odroid is dead. | **Battery warning** |
| **Red** | 🔴 | **Hardwired to safety chain** | Wired in parallel with contactor coil or watchdog relay. If safety chain broken (e-stop or watchdog), Red lights up. No software involved. | **Robot is safed / will not move** |

**Hardware:** 3× industrial 12mm panel-mount LED indicators (5V, integrated resistor), drilled into rear DiBond panel.

> [!IMPORTANT]
> **Defense in depth:** Red LED works with no software at all (pure hardware). Yellow LED works with only the Arduino alive (no Odroid needed). Green LED requires the full stack. If you see Red + Yellow + no Green, you know exactly what layer failed.

### CDR-12 Status: ✅ RESOLVED

BOM additions: 3× panel-mount LEDs ($3 total), wiring ($1). **Total: ~$4.**

---

## CDR-13: No Main Fuse on HV Bus (NEW) 🔴 CONFIRMED — CRITICAL SAFETY

> [!CAUTION]
> **There is no fuse anywhere between the battery and the VESCs.** This is arguably the most basic electrical safety requirement in any high-current system, and it is completely absent from the design. The BMS is the *backup*; the fuse is the *primary* defense.

### The Failure Mode

Without a fuse, the only overcurrent protection is the BMS internal MOSFET (which may or may not have a fast enough trip curve) and the wire insulation itself. In a hard short (e.g., a motor phase wire chafes through insulation against the aluminum frame):

1. Short circuit current: **hundreds of amps** (limited only by battery internal resistance and wire resistance)
2. 10-12 AWG wire at 200A+ → insulation melts in **<2 seconds**
3. If the BMS doesn't trip fast enough → **the wire IS the fuse** → arc flash → fire

This is how garage fires start in the e-bike and RC community.

### The Fix: High-Voltage MIDI Fuse Assembly (Consultant Validated)

#### Load Analysis (justifying 60A rating):

| Condition | Per Motor | 4× Motors Total |
|:---|:---|:---|
| Nominal driving (~350W @ 36V) | ~10A | **~40A continuous** |
| Peak stall/skid-turn (~700W @ 36V) | ~20A | **~80A peak** |

A 60A MIDI fuse is **slow-blow**: holds 60A indefinitely, holds ~90A (150%) for several seconds before blowing. This handles brief 80A skid-turn peaks without nuisance blowing.

#### Fuse Specification:

| Spec | Value |
|:---|:---|
| Fuse type | **Bolt-down MIDI / AMI fuse** (positive mechanical connection, won't vibrate loose) |
| Rating | **60A** (consultant validated — slow-blow handles 80A peaks) |
| Voltage | **≥58V DC rated — CRITICAL** |
| Recommended part | **Littelfuse 498 series** or equivalent industrial/marine grade |
| Holder | Inline MIDI fuse holder with protective cover, 10AWG ring terminals |
| Placement | **Immediately after the battery XT90-S connector** |
| Cost | ~$5 (fuse) + ~$8 (holder) = **$13** |

> [!CAUTION]
> **DO NOT buy standard auto parts store MIDI fuses.** Most automotive MIDI fuses are rated for **32V DC only** (car electrical systems). At 42V full charge, a 32V-rated fuse trying to interrupt a dead short **may not extinguish the arc** — the fuse blows but electricity jumps the gap, sustaining the fault. **Specify ≥58V DC rated fuses explicitly.**

#### Wire Gauge Constraint:

A fuse protects the *wire*, not the electronics. To safely use a 60A fuse:
- Main battery feeder wires must be **≥10AWG high-strand silicone wire (200°C rated)**
- If using thinner 12AWG wire, the wire might overheat before the fuse blows in a partial short

**Carry spares:** Keep 3× spare fuses in the maintenance kit. If a fuse blows, it means something else is broken — don't just replace the fuse without finding the root cause.

> [!IMPORTANT]
> **Fuse placement rule:** The fuse must be the FIRST component after the battery connector. The wiring path is:
> `Battery → XT90-S → MIDI Fuse → Bus Bar / Distribution → VESCs + DC-DC + Contactor`
>
> If the fuse is downstream of any junction, an unfused branch can still short.

### CDR-13 Status: ✅ RESOLVED

BOM additions: 1× 60A MIDI fuse ≥58V rated ($5), 1× inline holder ($8), 3× spare fuses ($10). **Total: ~$23.**

---

## Summary: Final Priority Triage

| # | Issue | Severity | Status | Cost | Resolution |
|:---|:---|:---|:---|:---|:---|
| CDR-1 | Bearing wear | 🟡 | ✅ | $0 | SKF 2RS seals + 50km maintenance |
| CDR-2 | Axle fatigue | 🟡 | ✅ | $0 | ≥2mm fillet radii + 304 SS option |
| CDR-3 | Vibration isolation | 🔴 | ✅ | $17 | Shore 40A bobbins + bonded washers + service loops |
| CDR-4 | CTE mismatch | 🟡 | ✅ | $16 | Hybrid TIM: pad at Cu-Al, paste at Cu-die |
| CDR-5 | Regen braking | 🔴 | ✅ | $35 | 200W 8Ω brake resistor + 60V/25A SSR |
| CDR-6 | No E-stop/watchdog | 🔴 | ✅ | $18 | Safety chain + USB-serial Arduino heartbeat |
| CDR-7 | CAN bus SPOF | 🟡 | ✅ | $5 | Daisy-chain STP + 120Ω termination |
| CDR-8 | DC-DC mismatch | 🔴 | ✅ | $10Δ | DDR-60L-15 (18–75V in, trim to 17V) |
| CDR-9 | Mass retention | 🔴 | ✅ | $12 | Battery floor + straps + XT90-S |
| CDR-10 | No graceful shutdown | 🟡 | ✅ | $0.20 | Arduino voltage divider + daemon |
| CDR-11 | No charge port | 🟡 | ✅ | $16 | Weipu SP17 IP68 connector + 10A fuse |
| CDR-12 | No status LEDs | 🟢 | ✅ | $4 | R/Y/G traffic light driven by Arduino + safety chain |
| CDR-13 | No main fuse | 🔴 | ✅ | $23 | 60A MIDI fuse ≥58V DC (Littelfuse 498) |

**Total cost of all fixes: ~$156.** No architectural changes required.

**The Arduino Nano ($3) is now the single most critical component** — it runs:
- Heartbeat watchdog (CDR-6)
- Contactor relay control (CDR-6)
- Battery voltage monitoring (CDR-10)
- Graceful shutdown triggering (CDR-10)
- Green + Yellow LED control (CDR-12)

---

## ⚠️ FINAL BLOCKER: Integrated Wiring Harness Diagram

> [!CAUTION]
> **Do NOT begin assembly without a complete wiring diagram.** Every subsystem from these 13 CDRs (safety chain, HV bus, CAN bus, voltage monitoring, charge port, status LEDs) must be drawn on one sheet to ensure correct interaction and proper ground management.

---

*Independent Critical Design Review — Engineering Partner*
*Date: 2026-02-07*
*Methodology: Adversarial failure mode analysis across all subsystems*
*13 CDRs identified, analyzed, and resolved through three-way review*
*CDR-13 added at consultant recommendation — main fuse missing from HV bus*

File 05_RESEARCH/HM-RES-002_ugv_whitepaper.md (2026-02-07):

# ENGINEERING ARCHITECTURE OF ASYMMETRIC GROUND ROBOTICS (UGV)
**ID:** HM-RES-002
**Status:** REFERENCE (Assimilated into [HM-CAT-001](../02_CATALOG/HM-CAT-001_master_design.md))
**Role:** Technical Theory & Physics Background

---

This design document synthesizes open-source intelligence (OSINT), field engineering reports, and robotics research from the Ukrainian theater (2022–2026). It is structured as a technical white paper for robotics engineers, focusing on the physics, component selection, and "battle-hardened" design patterns that have evolved from the conflict.

# 

---

**WHITE PAPER: ENGINEERING ARCHITECTURE OF ASYMMETRIC GROUND ROBOTICS (UGV)**

**Subject:** Technical Analysis of Ukrainian Combat Robotics (Classes: Loitering Munition, Logistics, ISR)

**Classification:** OPEN SOURCE / TECHNICAL REFERENCE

**Operational Context:** GPS-Denied, EW-Saturated, High-Plasticity Soil (*Chernozem*)

## 

---

**1.0 EXECUTIVE SUMMARY: THE "ATTRITABLE" DOCTRINE**

The conflict in Ukraine has invalidated the Western doctrine of complex, multi-role UGVs (e.g., Rheinmetall Mission Master) in favor of **single-mission, attritable platforms**. The dominant design philosophy is **"Capability per Dollar"**—a platform must cost less than the target it destroys or the logistics chain it replaces.

**Core Engineering Axioms:**

1. **Spectral Silence:** RF emissions are a distinct failure point. Autonomy, frequency hopping, or physical tethering (fiber optics) is mandatory.

2. **Terramechanics First:** The "Rasputitsa" (deep mud) dictates that **Ground Pressure must be &lt; 3.5 psi (24 kPa)**.

3. **The "Garage" Supply Chain:** Designs rely on dual-use COTS (Commercial Off-The-Shelf) components—drone motors, e-bike controllers, and industrial automation sensors—rather than ITAR-restricted defense hardware.

## 

---

**2.0 MECHANICAL ENGINEERING & DYNAMICS**

### **2.1 Terramechanics: Solving for "Rasputitsa"**

Ukrainian black soil (*Chernozem*) behaves as a cohesive-frictional plastic material. Traditional skid-steering requires immense torque to overcome the **Moment of Resistance (**<span data-latex="M_r" data-evaluate="no" data-display="no" data-type="inlineMath">$M_r$</span>**)** during turning, which spikes exponentially in deep mud due to the "bulldozing" effect of lateral soil displacement.

- **Design Constraint (Bekker-Wong Model):**\
  To prevent immobilization, the vehicle's contact patch must satisfy the pressure-sinkage relationship:\
  <span data-latex="p = \left( \frac{k_c}{b} + k_{\phi} \right) z^n" data-evaluate="no" data-display="yes" data-type="inlineMath">$$p = \left( \frac{k_c}{b} + k_{\phi} \right) z^n$$</span>

- *Where:* <span data-latex="p" data-evaluate="no" data-display="no" data-type="inlineMath">$p$</span> is pressure, <span data-latex="b" data-evaluate="no" data-display="no" data-type="inlineMath">$b$</span> is track/wheel width, <span data-latex="z" data-evaluate="no" data-display="no" data-type="inlineMath">$z$</span> is sinkage, and <span data-latex="n" data-evaluate="no" data-display="no" data-type="inlineMath">$n$</span> is the soil deformation exponent (0.3–0.5 for wet clay).

- **Implication:** Narrow wheels create "rut lock." **Wide pneumatic tires (balloon tires)** or **conveyor-belt tracks** are mandatory to increase <span data-latex="b" data-evaluate="no" data-display="no" data-type="inlineMath">$b$</span> and reduce <span data-latex="z" data-evaluate="no" data-display="no" data-type="inlineMath">$z$</span>.

- **Traction Physics (Janosi-Hanamoto Shear):**\
  Slick tires fail instantly. To mobilize soil shear strength, the tread design must use deep paddles (&gt;25mm).

- *Field Hack:* Ukrainian engineers often bolt aluminum U-channel profiles horizontally across rubber conveyor belts to create aggressive grousers that self-clean.

### **2.2 Chassis Topology & Materials**

- **The "Disposable" Class (Kamikaze/Mine-Laying):**

- **Material:** **Mild Steel Square Tubing (20x20mm, 2mm wall)**.

- **Why:** Unlike aluminum, steel absorbs vibration better without fatigue cracking and can be repaired in forward trenches using standard stick welders. Weight is an asset for traction.

- **The "Logistics" Class (Medevac/Resupply):**

- **Material:** **6061-T6 Aluminum** rails with **HDPE (High-Density Polyethylene)** body panels. HDPE is RF-transparent, waterproof, and does not shatter into shrapnel when hit.

- **Armor:** **Hardox 450/500** wear plates (4-6mm) are used *only* to shield the battery and compute core.

## 

---

**3.0 PROPULSION & POWER ELECTRONICS**
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

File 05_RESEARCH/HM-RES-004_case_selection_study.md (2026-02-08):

---
ID: HM-RES-004
Status: ACTIVE
Date: 2026-02-07
Role: Electronics Volume Analysis & Case Selection Study
Architecture: Nomad-T G30 Standard (Rev 3.2)
Linked: HM-RES-003, HM-CAT-009, HM-CAT-016
---

# Electronics Volume Analysis & Case Selection

> [!CAUTION]
> **FINDING: The Apache 2800 is too small.** The Odroid H4 Ultra alone is 120×120mm. The Apache 2800 internal width is 229mm. Fitting the Odroid + 4× VESCs on a single thermal deck plate inside the 2800 lid is physically impossible. This analysis recommends the **Apache 3800** as the optimal upgrade.

---

## 1. Complete Electronics Inventory with Dimensions

Every electronic component that must be protected in the enclosure:
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

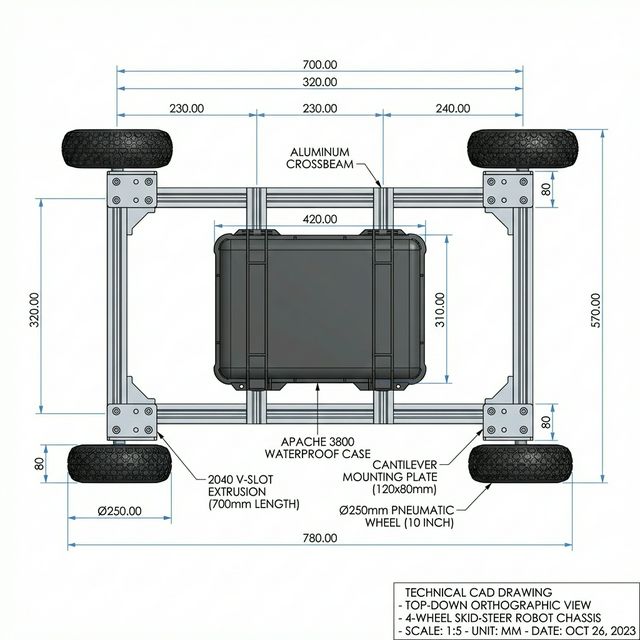
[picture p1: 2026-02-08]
04_ASSETS/images/cad/cad_chassis_top_view.png

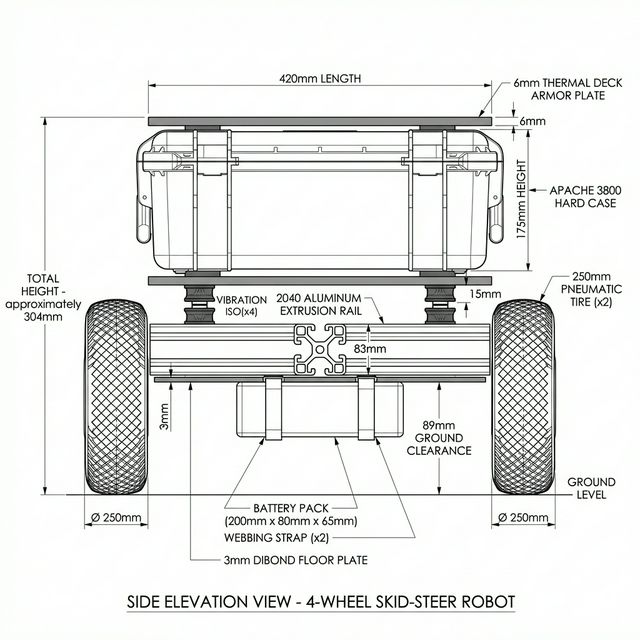
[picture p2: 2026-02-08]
04_ASSETS/images/cad/cad_chassis_side_view.png

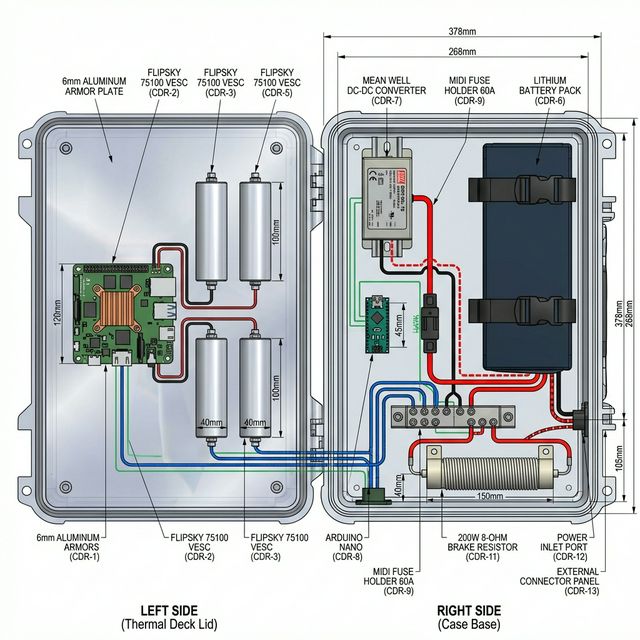
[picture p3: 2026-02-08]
04_ASSETS/images/cad/cad_electronics_bay.png

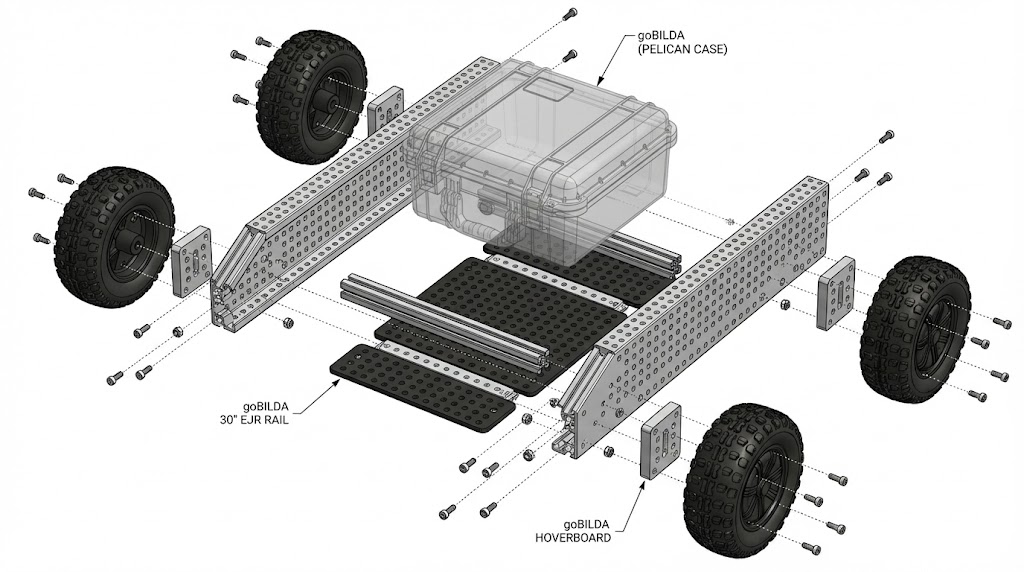
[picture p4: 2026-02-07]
04_ASSETS/HM-AST-003_chassis_exploded.jpg

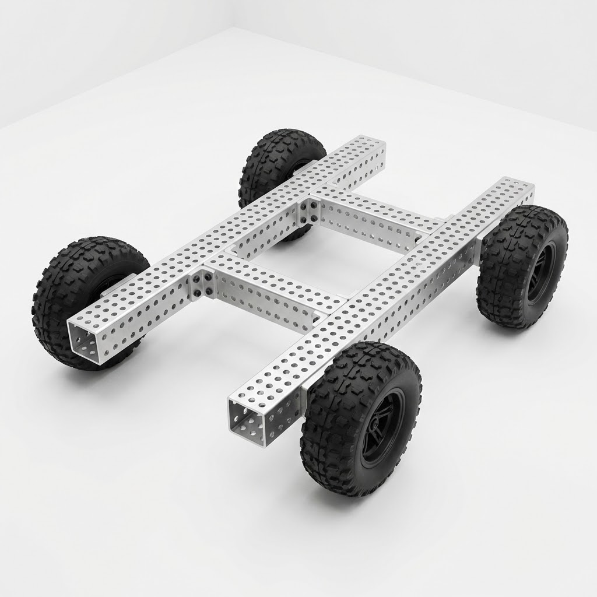
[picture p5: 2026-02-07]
04_ASSETS/HM-AST-001_chassis_main.jpg

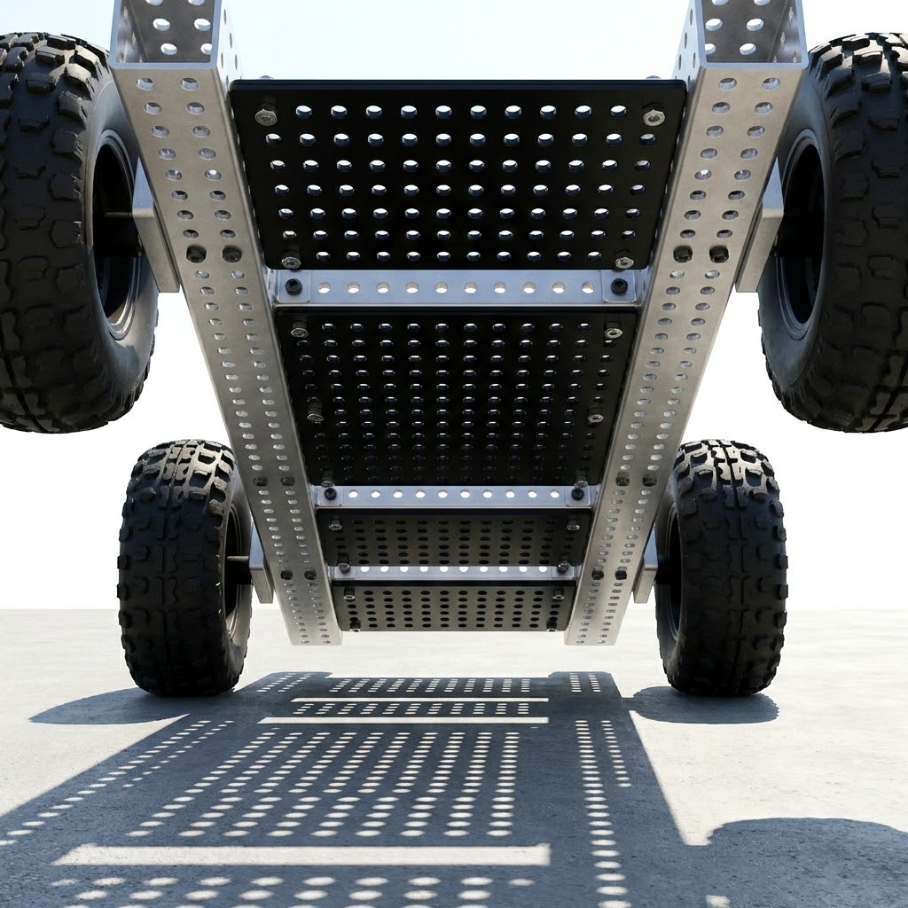
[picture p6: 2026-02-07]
04_ASSETS/HM-AST-002_chassis_under.jpg

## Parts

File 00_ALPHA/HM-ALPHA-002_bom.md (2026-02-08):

---
ID: HM-ALPHA-002
Status: ACTIVE
Version: Mk.0 "Scrapper"
Date: 2026-02-08
Role: Alpha Prototype Bill of Materials
Linked: HM-ALPHA-001
---

# Mk.0 "Scrapper" — Shopping List

> **Target: <$500.** Junkyard motors + AliExpress hardware + reusable electronics.

---

## 1. Salvaged Parts (Facebook Marketplace / Craigslist / Thrift)

| Item | What You're Harvesting | Qty | Est. Cost |
|:--|:--|:--|:--|
| **Broken Hoverboard** | 2× motors + tires + Hall cables | 2 boards | **$40** |
| **Hoverboard Battery** (Optional) | 36V 10S2P Li-Ion pack + BMS | 1 | **$0** (from board) |

> [!TIP]
> **How to spot a good donor board:**
> - Listing says "won't turn on" or "won't charge" = dead battery or BMS. Motors are fine.
> - Listing says "one side doesn't work" = dead gyro board. Motors are fine.
> - Listing says "motor grinding" = **SKIP** (actual motor damage, rare).
> - Bonus: Some boards include chargers. The charger is 42V (10S) — you can reuse it.

---

## 2. Frame & Hardware (AliExpress)

| Item | Spec | Qty | Est. Cost |
|:--|:--|:--|:--|
| 2040 V-Slot Extrusion | 700mm length | 2 | $12 |
| 2040 V-Slot Extrusion | 1000mm (cut to 240mm) | 1 | $6 |
| M5 × 10 BHCS + T-Nuts | 2040 fasteners (bag of 50) | 1 | $6 |
| Interior Corner Brackets | 2040 L-bracket | 12 | $5 |
| M4 × 15 SHCS | Motor mounting bolts | 16 | $3 |

**Subtotal: ~$32**

---

## 3. Motor Mounting (Choose One)

### Option A: 3D Printed (Fastest, $2)
- Print 4× L-brackets in PETG, 100% infill
- Bolt motor M4 face to bracket, bolt bracket to 2040 T-slot
- **Lifespan:** ~50 hours of testing

### Option B: Aluminum Flat Bar ($10)
- Buy 25mm × 3mm aluminum flat bar from hardware store
- Cut and drill 4× L-brackets
- More durable, slightly more effort

---

## 4. Electronics (Reusable — Carries to Mk.1)

| Item | Spec | Qty | Est. Cost | Source |
|:--|:--|:--|:--|:--|
| **VESCs** | Flipsky 75100 | 4 | $260 | Flipsky / AliExpress |
| **DC-DC** | Mean Well DDR-60L-15 | 1 | $35 | DigiKey |
| **USB-CAN** | TouCAN or similar | 1 | $30 | Amazon |
| **Odroid H4 Ultra** | Already purchased | 1 | $0 | — |
| **RAM** | 16GB DDR5 SO-DIMM | 1 | $0 | Already purchased |

**Subtotal: ~$325**

---

## 5. Safety & Wiring

| Item | Spec | Qty | Est. Cost | Source |
|:--|:--|:--|:--|:--|
| E-Stop Button | NC Mushroom, panel mount | 1 | $8 | AliExpress |
| Blade Fuse + Holder | 40A ATC | 1 | $3 | Auto parts / Amazon |
| XT60 Connectors | Battery disconnect | 2 pairs | $3 | AliExpress |
| 12 AWG Silicone Wire | Red + Black (2m each) | 1 | $5 | AliExpress |
| 18 AWG Wire | Signal / Logic (assorted) | 1 | $4 | AliExpress |
| Arduino Nano | Watchdog + LED driver | 1 | $5 | AliExpress |

**Subtotal: ~$28**

---

## 6. Optional but Recommended

| Item | Spec | Qty | Est. Cost | Notes |
|:--|:--|:--|:--|:--|
| RC Receiver + Transmitter | FlySky FS-i6X | 1 | $45 | Manual override / teleop |
| Joystick (USB) | Logitech F710 | 1 | $30 | ROS 2 teleop_twist_joy |
| Anti-tip Casters | 1" swivel caster | 2 | $5 | Prevents face-plants on hard braking |

---

## Grand Total

| Category | Cost |
|:--|:--|
| Salvaged Parts | $40 |
| Frame & Hardware | $32 |
| Motor Mounting | $5 |
| Electronics (Reusable) | $325 |
| Safety & Wiring | $28 |
| **Total (Required)** | **~$430** |
| Optional (RC/Joystick) | +$80 |
| **Total (Full Kit)** | **~$510** |

> [!IMPORTANT]
> **$325 of this carries forward to Mk.1 unchanged.** The actual "throwaway" cost of the Alpha is only ~$105 (motors + frame hardware + brackets).

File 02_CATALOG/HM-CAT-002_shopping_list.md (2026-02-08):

---
ID: HM-CAT-002
Status: ACTIVE
Role: Master Shopping List (Phase 1)
Date: 2026-02-07
Linked: HM-CAT-001, HM-CAT-012, HM-CAT-014
---

# Nomad-T Phase 1 Shopping List

> [!NOTE]
> **VERIFIED BOM.** This list aligns with the "Rigid 2040 + G30 Hub Motor" architecture. Costs are estimates.

## 1. Drivetrain & Structure (The "Physical" Bot)

> [!TIP]
> **Sourcing Rule:** AliExpress is fine for all structural/hardware parts. Only the G30 motors require OEM sourcing (CDR-1 "Golden Unit" rule).

| Item | Spec | Qty | Est. Cost | Source |
| :--- | :--- | :--- | :--- | :--- |
| **Hub Motors** | Ninebot Max G30 (Gen 2) **Rear** | 4 | $240 ($60 ea) | eBay / MSP (OEM Only) |
| **Frame Rails** | 2040 V-Slot Extrusion (700mm) | 2 | $12 | AliExpress |
| **Crossbeams** | 2040 V-Slot Extrusion (1000mm stick, cut to 240mm) | 1 | $6 | AliExpress |
| **Chassis Main Case** | Apache 3800 (Black) | 1 | $40 | Harbor Freight |
| **Shear Panels** | 3mm DiBond / ACP Sheet (12" x 24") | 2 | $20 | AliExpress / Amazon |
| **Vibration Mounts** | M5 Rubber Bobbin (Shore 40A) | 4 | $5 | AliExpress |
| **Motor Plates** | 6mm Aluminum (Laser/Waterjet Svc) | 4 | $50 | SendCutSend |

**Subtotal: ~$373**

## 2. Power System (36V)

| Item | Spec | Qty | Est. Cost | Source |
| :--- | :--- | :--- | :--- | :--- |
| **Battery** | 36V 10S3P (or 10S4P) Li-Ion | 1 | $120 | Battery Hookup / M365 |
| **Main Fuse** | 60A MIDI Fuse + Holder | 1 | $10 | Amazon / Auto |
| **Connectors** | XT90-S (Anti-Spark) Pair | 2 | $8 | Amazon |
| **DC-DC Converter** | Mean Well DDR-60L-15 | 1 | $35 | DigiKey / Mouser |
| **Wire** | 10 AWG Silicone (Red/Black) | 10ft | $15 | Amazon |

**Subtotal: ~$188**

## 3. Control & Safety

| Item | Spec | Qty | Est. Cost | Source |
| :--- | :--- | :--- | :--- | :--- |
| **VESC** | Flipsky 75100 (Aluminum PCB) | 4 | $260 ($65 ea) | Flipsky / Amazon |
| **E-Stop** | N.C. Mushroom Button | 1 | $10 | Amazon |
| **Relay Module** | 5V Relay (for Watchdog) | 1 | $5 | Amazon |
| **Contactor** | 12V Coil / 100A DC | 1 | $25 | Amazon / Auto |
| **Brake Resistor** | 200W 8Ω Chassis Mount | 1 | $15 | Amazon |

**Subtotal: ~$315**

## 4. Compute & Sensors (The "Brains")

| Item | Spec | Qty | Est. Cost | Source |
| :--- | :--- | :--- | :--- | :--- |
| **SBC** | Odroid H4 Ultra | 1 | $239 | Ameridroid |
| **RAM** | 16GB DDR5 SO-DIMM | 1 | $45 | Amazon |
| **SSD** | 256GB NVMe M.2 | 1 | $30 | Amazon |
| **LiDAR** | RPLiDAR C1 | 1 | $150 | RobotShop |
| **Camera** | OAK-D Lite | 1 | $150 | Luxonis |
| **Interface** | USB-CAN Adapter (TouCAN/Poly) | 1 | $30 | Amazon |

**Subtotal: ~$644**

## 5. Hardware & Misc

| Item | Spec | Qty | Est. Cost | Source |
| :--- | :--- | :--- | :--- | :--- |
| **M5 Screws** | M5x10, M5x15, M5x40 (Box) | 1 | $6 | AliExpress |
| **T-Nuts** | M5 Drop-in for 2020/2040 | 50 | $4 | AliExpress |
| **Thermal Pad** | 100mm x 100mm (0.5mm) | 1 | $3 | AliExpress |
| **Cable Glands** | PG7 / PG9 Assortment | 1 | $4 | AliExpress |
| **Corner Brackets** | 2040 Interior L-Bracket | 20 | $6 | AliExpress |

**Subtotal: ~$23**

---

## Grand Total: ~$1,500 USD

*Note: AliExpress sourcing saves ~$100 vs domestic. Budget includes shipping buffer. Well under $2,000 target.*

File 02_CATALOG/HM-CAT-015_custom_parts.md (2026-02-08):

---
ID: HM-CAT-015
Status: ACTIVE
Role: Custom Part Specification (NMT-MP-001)
Date: 2026-02-07
Linked: HM-CAT-010, HM-CAT-013
---

# Custom Part: NMT-MP-001 (Motor Plate)

> [!CRITICAL]
> **The linchpin of the design.** This plate adapts the G30's "Double-D" axle to the 2040 frame. Failure here means a wheel falls off.

## 1. Geometry

*   **Material:** 6061-T6 Aluminum (Assessment: Sufficient) or 304 Stainless (Overkill but durable).
*   **Thickness:** **6.0mm** (Match axle flat length).
*   **Overall Size:** ~80mm x 80mm (Triangular/Trapezoidal gusset shape).

## 2. The "Double-D" Output Slot (CDR-2)

*   **Shaft Diameter:** 12.0mm
*   **Flat-to-Flat:** 10.0mm
*   **Corner Radii:** **R2.0mm (Min)** in the corners of the slot.
    *   *Why?* Sharp corners create stress risers that will crack under 30Nm torque cycles.

## 3. Frame Interface

*   **Bolt Pattern:** 4x M5 Clearance Holes (5.5mm).
*   **Spacing:** 20mm grid to match V-Slot end profile (tapped holes) or side T-slots.
*   **Fasteners:** M5 x 15mm Socket Head Cap Screws.

## 4. Fabrication Notes

*   **Process:** Waterjet or Laser Cut.
*   **Tolerance:** +/- 0.1mm on the Axle Slot. (Loose = Slop/Wear, Tight = Won't fit).
*   **Post-Process:** Deburr edges. Ream slot if necessary for snug fit.

## 5. Quantity

*   **Total:** 4 Plates (1 per wheel).
*   **Spares:** Order 6 (2 spares recommended).

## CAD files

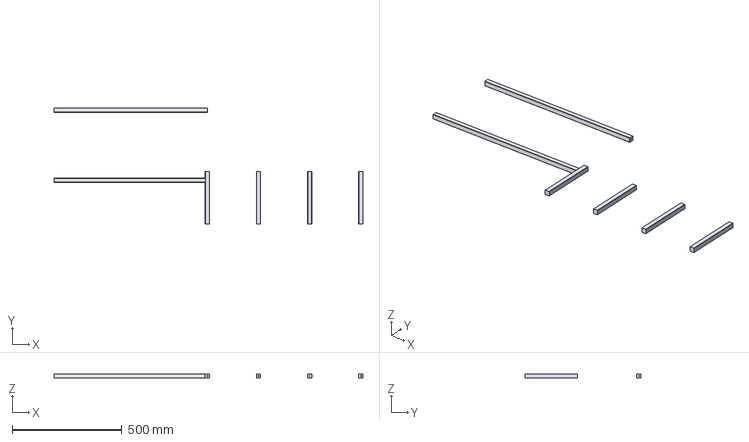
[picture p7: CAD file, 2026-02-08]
04_ASSETS/cad/parts/NMT-FR-001_frame_assembly.step
1410.0 x 530.0 x 20.0 mm
rail_L x 2
xbeam_1 x 4

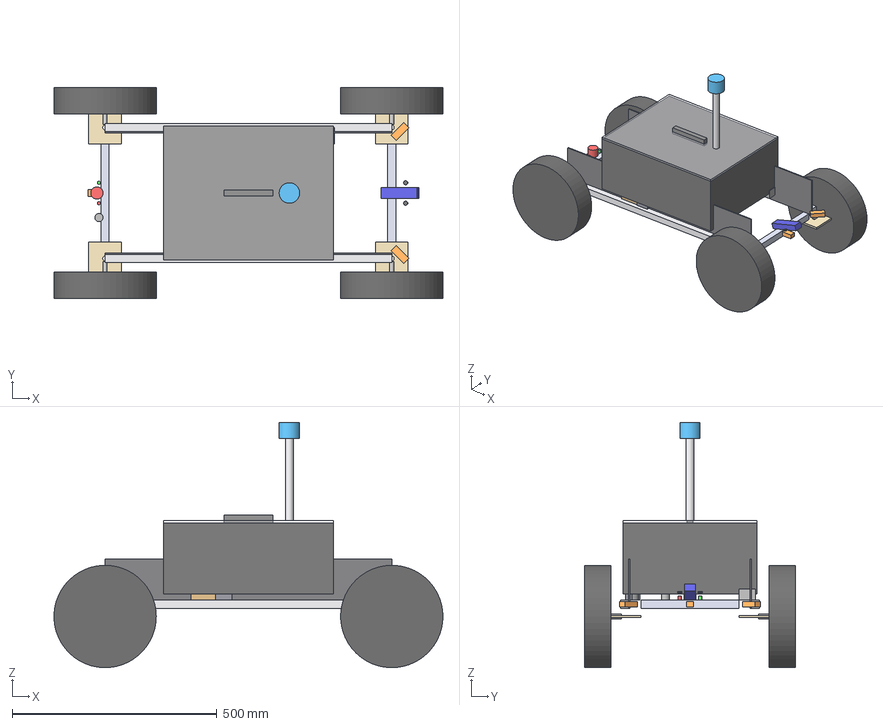
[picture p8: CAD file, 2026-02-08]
04_ASSETS/cad/HM-AST-006_nomad_t_chassis.step
949.8 x 515.0 x 598.9 mm
rail_L x 2
xbeam_1 x 4
shear_L x 2
motor_plate_FL x 4
g30_hub_FL_tire x 4
g30_hub_FL_motor x 4
g30_hub_FL_axle x 4
bobbin_FL x 4
apache_3800
case_handle
battery_10s3p
battery_xt90
thermal_deck
vesc_FL x 4
lidar_mast
rplidar_c1
oakd_lite
oakd_lens_L x 3
ir_FL x 4
imu_wt901
brake_resistor
dcdc_meanwell
arduino_nano
estop_button
distribution_bus
main_contactor
led_green
led_yellow
led_red
charge_port

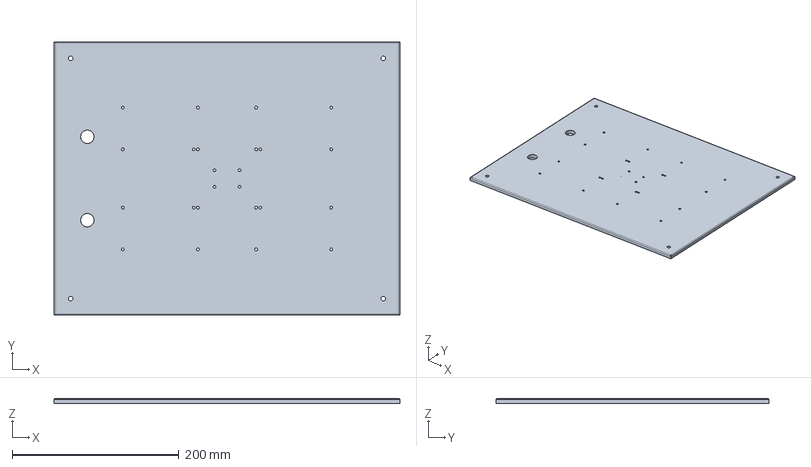
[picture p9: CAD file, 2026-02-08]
04_ASSETS/cad/parts/NMT-TD-001_thermal_deck.step
415.0 x 328.0 x 6.00 mm

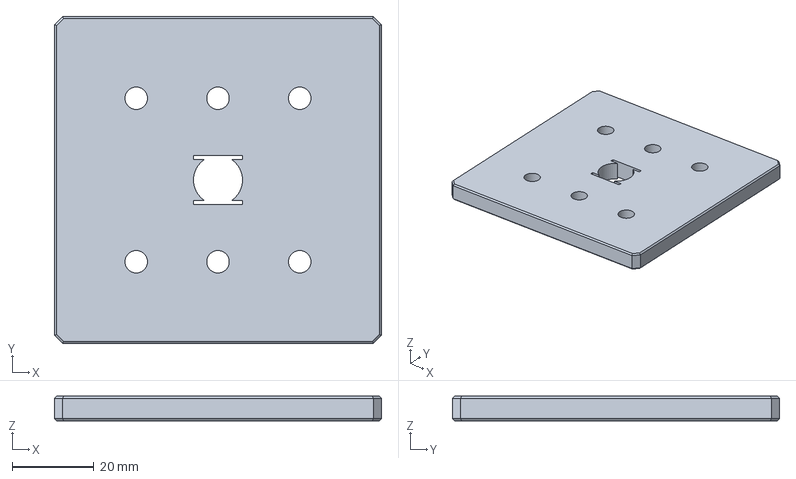
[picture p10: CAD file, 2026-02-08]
04_ASSETS/cad/parts/NMT-MP-001_motor_plate.step
80.0 x 80.0 x 6.00 mm

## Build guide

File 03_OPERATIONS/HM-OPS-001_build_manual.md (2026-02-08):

---
ID: HM-OPS-001
Status: ACTIVE
Date: 2026-02-08
Role: Assembly & Build Manual
Linked: HM-DWG-001, HM-CAT-002, HM-CAT-015
---

# Nomad-T Phase 1 — Build Manual

> [!CAUTION]
> **Read HM-OPS-002 (Safety Manual) before beginning.** Li-Ion batteries and 36V systems can cause burns, fire, and electrical shock if mishandled.

---

## Required Tools

| Tool | Size | Purpose |
|:---|:---|:---|
| Hex Key Set | 2.5, 3, 4, 5mm | Frame bolts, motor plates |
| Torque Wrench | M5 range (4-8 Nm) | Critical fasteners |
| Wire Strippers | 10-22 AWG | Wiring harness |
| Crimping Tool | Ferrules + Ring Terminals | Power connections |
| Multimeter | DC Volts + Continuity | Verification |
| Heat Gun | — | Heat shrink, cable management |
| Drill + Bits | 5mm, 8mm | Mounting holes (if needed) |
| Thread Locker | Loctite 243 (Medium) | Anti-vibration bolts |

---

## Phase 1: Frame Assembly

### Step 1.1 — Cut Extrusion

| Part | Profile | Length | Qty |
|:---|:---|:---|:---|
| Side Rails | 2040 | 700mm | 2 |
| Crossbeams | 2040 | 240mm | 4 |

**Verification:** Measure each piece ±1mm. Deburr all cuts.

### Step 1.2 — Assemble Frame

1. Lay both 700mm rails parallel, 240mm apart (inside edge to inside edge).
2. Insert M5 T-Nuts into the rail channels (top and side slots).
3. Bolt crossbeams at front, rear, and two intermediate positions using M5 × 10mm BHCS.
4. **Torque:** 5 Nm for all frame bolts.
5. **Square Check:** Measure diagonals. Must be equal ±2mm.

### Step 1.3 — Install Shear Panels

1. Cut 3mm DiBond to 700mm × 120mm (2 panels).
2. Drill M5 clearance holes at 100mm intervals along the panel edges.
3. Bolt panels to the **outer face** of the side rails using M5 × 15mm + T-Nuts.
4. **Purpose:** Prevents frame parallelogramming under torque steer.

**✅ CHECKPOINT:** Frame is rigid, square, and panels are flush.

---

## Phase 2: Drivetrain Installation

### Step 2.1 — Install Motor Plates (NMT-MP-001)

> **Reference:** [HM-CAT-015](../02_CATALOG/HM-CAT-015_custom_parts.md) for plate drawing.

1. Attach one motor plate to each end of each side rail (4 total).
2. Bolt pattern: 4× M5 × 15mm into rail end-face tapped holes.
3. **Torque:** 6 Nm + **Loctite 243** (vibration-critical joint).
4. Verify the "Double-D" slot is oriented with flats **vertical**.

### Step 2.2 — Mount Hub Motors

1. Slide Ninebot G30 axle into the motor plate slot.
2. Apply axle nut and torque washer on the outboard side.
3. **Torque:** Per OEM spec (typically 25-30 Nm for M12 axle nuts).
4. **Spin Test:** Each wheel must rotate freely with no wobble or grinding.

**✅ CHECKPOINT:** All 4 wheels spin freely. Robot sits level on flat surface.

---

## Phase 3: Electrical — Power System

> **Reference:** [HM-DWG-001](../06_ENGINEERING/01_SCHEMATICS/HM-DWG-001_wiring_harness.md)

### Step 3.1 — Install Main Fuse

1. Bolt 60A MIDI Fuse Holder to the Apache 3800 case base (near battery bay).
2. Connect Battery XT90-S (+) → Fuse Input with **10 AWG Red** wire.
3. Connect Fuse Output → Distribution Bus Bar with **10 AWG Red** wire.
4. **Wire Length:** Keep battery-to-fuse run **<200mm** (CDR-13).

### Step 3.2 — Wire Distribution Bus

1. Mount positive and negative bus bars inside the Apache 3800 case base.
2. Connect Battery (-) to Negative Bus Bar with **10 AWG Black** wire.
3. Wire bus bar outputs per HM-DWG-001 Section 2A.

### Step 3.3 — Install DC-DC Converter (CDR-8)

1. Mount DDR-60L-15 to the case base with M3 screws.
2. Connect Input V+ and V- from Distribution Bus (16 AWG).
3. **Trim Output:** Adjust trim pot to **17.0V** using multimeter.
4. Connect output to Odroid H4 Ultra DC barrel jack (5.5×2.1mm).

### Step 3.4 — Wire Safety Loop

1. Wire E-Stop (NC) in series with the Relay Module output.
2. Connect Relay NO contact to Contactor Coil (+).
3. Connect Contactor Coil (-) to GND.
4. Connect Arduino D2 to Relay Module Signal input.
5. **Test:** Press E-Stop → Contactor should open (click sound). Release → No change until Arduino asserts D2.

### Step 3.5 — Wire VESCs

*Repeat for all 4 VESCs:*
1. Connect VESC V+ to Switched Power (Contactor Load Side) via 14 AWG Red.
2. Connect VESC GND to Negative Bus Bar via 14 AWG Black.
3. Connect 3× Motor Phase Wires (match wire colors, or detect in VESC Tool).
4. Connect Hall Sensor Cable (JST-PH 6-pin).

### Step 3.6 — Wire CAN Bus (CDR-7)

1. Daisy-chain CAN-H and CAN-L from USB-CAN adapter → VESC1 → VESC2 → VESC3 → VESC4.
2. Use **Shielded Twisted Pair** (STP).
3. Ground shield at USB-CAN adapter end **only**.
4. Solder **120Ω resistor** across CAN-H and CAN-L at VESC4 (end of chain).

**✅ CHECKPOINT:** Multimeter shows battery voltage at bus bars. DC-DC outputs 17.0V. E-Stop kills contactor.

---

## Phase 4: Electronics Integration

### Step 4.1 — Prepare Thermal Deck

1. Cut 6mm aluminum plate to Apache 3800 lid dimensions (378 × 268mm).
2. Machine/drill copper pedestal mounting pocket (for Odroid CPU contact).
3. Mount VESCs (×4) inverted on the underside of the plate using M3 screws.
4. Mount Odroid H4 Ultra inverted — CPU die contacts copper pedestal via thermal pad.

### Step 4.2 — Mount Case on Frame

1. Install 4× M5 Rubber Bobbins on the 2040 rail top slots.
2. Place Apache 3800 base on the bobbins.
3. Secure with M5 nuts through bobbin studs.
4. **Bounce Test:** Case should have ~2mm of give when pressed. This is the vibration isolation (CDR-3).

### Step 4.3 — Route External Cables

1. Install cable glands (PG7/PG9) in the Apache 3800 case wall.
2. Route motor phase wires, CAN bus, and sensor cables through glands.
3. Seal each gland finger-tight + ¼ turn with wrench.
4. **IP65 Check:** No cable should be pinched or unsealed.

**✅ CHECKPOINT:** Close case lid (Thermal Deck). All cables routed. No pinch points.

---

## Phase 5: First Power-On

> [!WARNING]
> **Follow HM-OPS-002 (Safety Manual) Section 3 — First Power-On Protocol.**

1. Ensure E-Stop is **pressed** (locked out).
2. Connect battery XT90-S.
3. Verify: Red LED = ON (Safety Active).
4. Use multimeter to check:
   - Bus Bar Voltage: 36-42V DC
   - DC-DC Output: 17.0V ± 0.2V
   - CAN Bus Resistance: ~60Ω (end-to-end, both terminators)
5. Release E-Stop. Assert Arduino watchdog. Contactor should close (click).
6. Verify: Green LED = OFF (ROS not running yet). Yellow LED behavior = TBD.
7. Power on Odroid. Wait for boot. SSH in.

**✅ CHECKPOINT: FIRST LIGHT.** Robot is alive.

---

## Appendix: Torque Specification Table

| Fastener | Location | Torque | Thread Lock |
|:---|:---|:---|:---|
| M5 × 10 BHCS | Frame crossbeams | 5 Nm | None |
| M5 × 15 BHCS | Motor plates to rails | 6 Nm | Loctite 243 |
| M5 × 15 BHCS | Shear panels | 5 Nm | None |
| M5 Bobbin Nut | Case isolation mounts | 4 Nm | Nyloc |
| M3 × 8 SHCS | VESC to Thermal Deck | 1.5 Nm | None |
| M3 × 8 SHCS | Odroid to Thermal Deck | 0.8 Nm | None |
| M12 Axle Nut | Motor axle to plate | 25 Nm | Nyloc |

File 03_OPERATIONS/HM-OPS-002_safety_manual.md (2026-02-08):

---
ID: HM-OPS-002
Status: ACTIVE
Date: 2026-02-08
Role: Safety Manual & Emergency Procedures
Linked: HM-RES-005 (CDR-6, CDR-11, CDR-13), HM-DWG-001
---

# Nomad-T Safety Manual

> [!CAUTION]
> **MANDATORY READING** before any work on the robot. This document defines the safety systems, emergency procedures, and handling protocols for a 36V Li-Ion powered mobile robot.

---

## 1. Hazard Summary

| Hazard | Source | Severity | Mitigation |
|:---|:---|:---|:---|
| **Electrical Shock** | 36V Battery (42V Max) | Moderate | XT90-S disconnect, MIDI fuse, E-Stop |
| **Thermal Burns** | VESCs under load, Brake Resistor | Low | Enclosed in case, thermal deck dissipates |
| **Pinch/Crush** | Moving wheels (30Nm torque) | High | E-Stop, Watchdog, Never reach under while powered |
| **Battery Fire** | Li-Ion thermal runaway | Severe | BMS protection, fuse, charge port fuse, steel cells |
| **Tip-Over** | Off-camber terrain, CG shift | Moderate | Speed limits, payload centering |

---

## 2. Safety Systems Architecture

### 2.1 Emergency Stop (CDR-6)

*   **Type:** Red Mushroom Button, Normally-Closed (NC)
*   **Location:** Rear panel, accessible without reaching over wheels
*   **Action:** Pressing E-Stop breaks the contactor coil circuit → Contactor opens → **All motor power is cut instantly**
*   **Reset:** Twist/Pull to release button → Power cycle Arduino → Watchdog re-asserts → Contactor closes
*   **Design Principle:** The E-Stop does NOT switch high current directly. It interrupts the low-current coil circuit.

### 2.2 Watchdog (CDR-6)

*   **Controller:** Arduino Nano (USB connected to Odroid)
*   **Heartbeat:** ROS node sends serial heartbeat every 500ms
*   **Timeout:** If no heartbeat for 2 seconds → Arduino de-asserts D2 → Relay opens → Contactor opens
*   **Fail-Safe:** Loss of USB, Odroid crash, or software hang = motors OFF

### 2.3 Main Fuse (CDR-13)

*   **Rating:** 60A MIDI Fuse, **≥58V DC Rated** (Littelfuse 498 series or equivalent)
*   **Location:** Immediately after battery XT90-S (<200mm wire length)
*   **Replacement:** Turn off battery (disconnect XT90-S) → Wait 30 seconds → Unbolt fuse → Replace with identical rating → Reconnect.
*   **Spare Fuses:** Carry 2× spares in the Apache 3800 case lid pocket.

> [!WARNING]
> **NEVER substitute a higher-rated fuse.** The 60A rating protects 10 AWG wire from fire. A higher fuse defeats the protection.

### 2.4 Charging Safety (CDR-11)

*   **Port:** Weipu SP17 (Rear Panel), fused at **10A**
*   **Charger:** 42V Li-Ion charger (10S), ≤5A output
*   **Procedure:**
    1. Press E-Stop (motors disabled)
    2. Connect charger to Weipu port
    3. Monitor BMS LED (if visible) or battery voltage via Arduino/Odroid
    4. Disconnect when BMS balance LED goes solid or voltage reaches 41.5V
    5. **Never charge unattended overnight**

---

## 3. First Power-On Protocol

> [!IMPORTANT]
> Perform this sequence for **every** first assembly or after any wiring change.

1. **Visual Inspection:**
   - [ ] All wires routed away from moving parts
   - [ ] No bare copper visible (all terminals insulated)
   - [ ] Fuse installed and correct rating visible
   - [ ] E-Stop is PRESSED (locked out)

2. **Cold Resistance Checks** (Battery NOT connected):
   - [ ] Battery (+) to Frame: > 1 MΩ (no short to chassis)
   - [ ] Battery (-) to Frame: > 1 MΩ
   - [ ] CAN Bus end-to-end: ~60Ω (with both terminators)

3. **Connect Battery:**
   - [ ] Plug XT90-S Anti-Spark connector slowly (expect small spark on anti-spark pin)
   - [ ] Red LED ON = Safety chain active (correct)
   - [ ] Measure Bus Bar voltage: 30-42V DC

4. **Logic Power Verify:**
   - [ ] DC-DC output: 17.0V ± 0.2V
   - [ ] Odroid power LED: ON

5. **Release E-Stop:**
   - [ ] Twist button to release
   - [ ] Power-cycle Arduino (disconnect/reconnect USB or reset button)
   - [ ] Listen for contactor CLICK (confirming closure)
   - [ ] Red LED OFF, Green LED behavior TBD

---

## 4. Emergency Procedures

### 4.1 Runaway Robot
1. **Press E-Stop** (if reachable)
2. If E-Stop not reachable: **pull the XT90-S battery connector**
3. If neither: **tip the robot on its side** (wheels off ground)

### 4.2 Battery Smoke / Swelling
1. **Disconnect battery immediately** (XT90-S)
2. Move battery to open air (concrete/dirt, NOT inside building)
3. Do NOT use water. Use **dry sand** or **Class D fire extinguisher**
4. Call emergency services if fire develops

### 4.3 Electrical Shock
1. **Do NOT touch the victim and the robot simultaneously**
2. Disconnect XT90-S using insulated gloves or a dry wooden stick
3. Administer first aid. Call 911 if needed.

---

## 5. Personal Protective Equipment (PPE)

| Item | When Required |
|:---|:---|
| **Safety Glasses** | All wiring and assembly work |
| **Insulated Gloves** | Battery connection/disconnection |
| **Closed-Toe Shoes** | All operations (robot weighs 19kg) |
| **Hearing Protection** | Not required (hub motors are silent) |

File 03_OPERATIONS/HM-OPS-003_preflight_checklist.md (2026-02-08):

---
ID: HM-OPS-003
Status: ACTIVE
Date: 2026-02-08
Role: Pre-Flight Checklist (Field Operations)
Linked: HM-OPS-002 (Safety), HM-DWG-001
---

# Nomad-T Pre-Flight Checklist

> **Laminate this page and keep it with the robot.**
> Complete EVERY item before EVERY field deployment.

---

## ✅ VISUAL INSPECTION

- [ ] Frame bolts: No loose or missing fasteners
- [ ] Motor plates: Axle nuts tight, no play
- [ ] Wheels: No cuts, bulges, or flat spots on tires
- [ ] Shear panels: No cracks, all bolts present
- [ ] Case: Latches closed, cable glands sealed
- [ ] Wiring: No chafing, exposed copper, or pinched cables

---

## ✅ TIRE PRESSURE

- [ ] All 4 tires inflated to **5-8 PSI** (Low = Off-road, High = Pavement)
- [ ] No visible deflation or soft spots

---

## ✅ BATTERY

- [ ] Battery voltage: **> 34V** (Measured at XT90-S before connecting)
- [ ] If < 34V: **CHARGE BEFORE DEPLOYING** (Yellow LED will warn)
- [ ] If < 32V: **DO NOT DEPLOY** — Deep discharge risk
- [ ] XT90-S connector: Clean, no melting, pins straight

---

## ✅ FUSE CHECK

- [ ] 60A MIDI Fuse: Visually intact (no discoloration or blown indicator)
- [ ] Fuse holder: Bolts tight, no corrosion
- [ ] Spare fuses: 2× stowed in case lid pocket

---

## ✅ SAFETY SYSTEMS

- [ ] E-Stop: **PRESSED** before connecting battery
- [ ] Connect battery → Red LED = ON (Safety Active)
- [ ] DC-DC Output: **17V** (Spot-check with multimeter if first run of the day)
- [ ] Release E-Stop → Contactor CLICKS → Red LED OFF
- [ ] Green LED: ON after ROS boot (wait 30-60 seconds)
- [ ] **Motor Test:** Briefly jog each wheel forward/reverse via teleop. Verify direction.

---

## ✅ COMMS CHECK

- [ ] WiFi connected: `ping <robot_ip>` from laptop
- [ ] SSH access: `ssh user@<robot_ip>`
- [ ] ROS topics: `ros2 topic list` shows expected topics
- [ ] Joystick/RC: Teleop responds to input

---

## ✅ SENSOR CHECK

- [ ] LiDAR: Spinning (audible/visual)
- [ ] Camera: `ros2 topic hz /camera/image_raw` > 0
- [ ] IMU: `ros2 topic echo /imu/data` — values change when tilted
- [ ] IR Sensors: Front/Rear respond to hand wave

---

## 🚀 CLEARED FOR DEPLOYMENT

**Date:** _______________
**Operator:** _______________
**Battery Voltage:** _______ V
**Weather:** _______________
**Notes:** _______________________________________________

---

## 🛑 POST-MISSION

- [ ] Press E-Stop
- [ ] Disconnect XT90-S
- [ ] Record battery voltage: _______ V
- [ ] Inspect tires for debris/damage
- [ ] Wipe down frame and sensors
- [ ] Charge battery if < 36V
- [ ] Log any anomalies: _______________________________________

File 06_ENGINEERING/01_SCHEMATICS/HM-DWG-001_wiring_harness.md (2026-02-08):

---
ID: HM-DWG-001
Title: Integrated Wiring Harness & Electrical Schematic
Status: DRAFT — FOR REVIEW
Date: 2026-02-07
Revision: 1.0
System: Nomad-T Field Robot
Reference: HM-RES-005 (CDR Findings)
---

# Nomad-T Integrated Wiring Harness

> [!CAUTION]
> **SAFETY CRITICAL DOCUMENT.** This schematic integrates all 13 Critical Design Review (CDR) findings. **Do not deviate** from fuse ratings, wire gauges, or safety loop topology without engineering approval.
>
> **Critical Safety Rules:**
> 1. Main Fuse (60A MIDI) must be **immediately** after battery XT90-S.
> 2. All 36V+ power lines must be **10AWG Silicone** minimum before the distribution block.
> 3. E-Stop breaks the **contactor coil** circuit, not the main power directly.
> 4. CAN Bus must be daisy-chained with **120Ω termination** at ends.

---

## 1. High-Level Architecture (Block Diagram)

```mermaid
graph TD
    %% Power Source
    Bat[("🔋 Battery<br/>10S3P Li-Ion<br/>36V 12Ah")] --> XT90{{"XT90-S<br/>Anti-Spark"}}
    XT90 --> Fuse[("🧨 Main Fuse<br/>60A MIDI<br/>(≥58V Rated)")]
    Fuse --> BusBar[("⚡ Distribution Bus<br/>36V High Current")]

    %% Charging (Bypasses Main Contactor)
    ChargePort(("🔌 Charge Port<br/>Weipu SP17")) --"10A Fuse"--> BMS_C["BMS Charge P-"]
    BMS_C -.-> Bat

    %% Safety Chain & Logic Power
    BusBar --> DCDC[("📉 DC-DC<br/>Mean Well DDR-60L-15")]
    DCDC --"17V Regulated"--> Odroid[("🧠 Odroid H4 Ultra<br/>Computer")]
    
    Odroid <--"USB"--> Arduino[("🤖 Arduino Nano<br/>Watchdog & IO")]
    Arduino --"5V Signal"--> Relay[("Relay Module<br/>Watchdog")]
    
    EStop(("🛑 E-STOP<br/>NC Switch")) --> Relay
    Relay --> ContactorCoil["Contactor Coil"]
    
    %% High Power Switching
    BusBar --> Contactor[("🔌 Main Contactor<br/>(Normally Open)")]
    ContactorCoil -.-> Contactor

    %% Drive System (Switched Power)
    Contactor == "36V Switched" ==> VESC1["VESC FL"]
    Contactor == "36V Switched" ==> VESC2["VESC FR"]
    Contactor == "36V Switched" ==> VESC3["VESC RL"]
    Contactor == "36V Switched" ==> VESC4["VESC RR"]

    %% Brake Shunt
    Contactor --> SSR[("SSR<br/>Solid State Relay")]
    SSR --> BrakeRes[("🔥 Brake Resistor<br/>200W 8Ω")]
    VESC1 -. "Regen Trig" .-> SSR

    %% CAN Bus Topology (Daisy Chain)
    Odroid --"USB-CAN"--> VESC1
    VESC1 <== "CAN Bus" ==> VESC2
    VESC2 <== "CAN Bus" ==> VESC3
    VESC3 <== "CAN Bus" ==> VESC4

    %% Status LEDs
    Arduino --"PWM"--> LED_Grn(("🟢 Green"))
    Arduino --"PWM"--> LED_Yel(("🟡 Yellow"))
    Relay -. "NO Contact" .-> LED_Red(("🔴 Red"))
```

---

## 2. Pin-to-Pin Wiring Netlist

### A. Main Power Path (HV Bus - 36V)

| From Component | Pin/Term | To Component | Pin/Term | Wire Sizing | Notes |
| :--- | :--- | :--- | :--- | :--- | :--- |
| **Battery Pack** | XT90-S (+) | **Main Fuse Holder** | Input Stud | **10 AWG Red** | <200mm length (CDR-13) |
| **Main Fuse Holder** | Output Stud | **Distribution Bus** | Positive Bar | **10 AWG Red** | |
| **Battery Pack** | XT90-S (-) | **Distribution Bus** | Negative Bar | **10 AWG Black** | |
| **Distribution Bus** | Positive | **Main Contactor** | Line Side (NO) | **10 AWG Red** | |
| **Main Contactor** | Load Side | **VESC Distribution** | Splice/Block | **10 AWG Red** | Switched HV+ |
| **Distribution Bus** | Positive | **DC-DC Input** | V+ | **16 AWG Red** | Always ON (logic power) |
| **Distribution Bus** | Negative | **DC-DC Input** | V- | **16 AWG Black** | |

### B. VESC Power & Motor Connections

*Repeat for all 4 motors (FL, FR, RL, RR)*

| From Component | Pin/Term | To Component | Pin/Term | Wire Sizing |
| :--- | :--- | :--- | :--- | :--- |
| **VESC Distribution** | Switched + | **VESC V+** | Input + | 14 AWG Red |
| **Distribution Bus** | Negative | **VESC GND** | Input - | 14 AWG Black |
| **VESC Phase A** | A | **Motor Phase** | Yellow | 16 AWG |
| **VESC Phase B** | B | **Motor Phase** | Green | 16 AWG |
| **VESC Phase C** | C | **Motor Phase** | Blue | 16 AWG |
| **VESC Hall** | 5V/GND/H1-H3 | **Motor Hall** | Connector | Proprietary |

> **Note:** G30 Motor Hall connector may need re-pinning to match VESC JST-PH 6-pin. (Verify pinout during Phase 1 bench test).

### C. Safety Loop & Watchdog Logic

**Concept:** The Main Contactor coil is powered by 5V from the Arduino via a Relay Module. The E-Stop button is wired in series with the Relay coil or the Contactor coil path to physically break the circuit.

**Safe State:** Logic LOW or Power Loss = Contactor OPEN (Motors OFF).

| Signal Name | Source | Dest | Wire | Logic |
| :--- | :--- | :--- | :--- | :--- |
| **Watchdog Trig** | Arduino D2 | Relay Module | Signal | High = CLOSED (Active) |
| **E-Stop Loop** | 5V Source | E-Stop Switch (NC) | 22 AWG | Physical Break |
| **Contactor Coil** | Relay NO | Contactor Coil (+) | 20 AWG | |
| **Contactor Coil** | GND | Contactor Coil (-) | 20 AWG | |

### D. CAN Bus Topology (Daisy Chain)

> **CDR-7 Compliance:** Use **Shielded Twisted Pair (STP)** (e.g., Cat5e routed pair). Shield grounded at one end only.

| Segment | From | To | Termination |
| :--- | :--- | :--- | :--- |
| **1** | USB-CAN Adapter (Odroid) | VESC 1 (FL) | |
| **2** | VESC 1 | VESC 2 (FR) | |
| **3** | VESC 2 | VESC 3 (RL) | |
| **4** | VESC 3 | VESC 4 (RR) | **120Ω Resistor** @ End |

### E. User Interface (Rear Panel)

| Component | Function | Connection | Logic |
| :--- | :--- | :--- | :--- |
| **Red LED** | "Safety Active" | Wired across E-Stop NC | ON when E-Stop pressed |
| **Yellow LED** | "Battery Warn" | Arduino D3 (PWM) | Blink <34V, Solid <32V |
| **Green LED** | "ROS Healthy" | Arduino D4 | ON when Heartbeat valid |
| **Charge Port** | Charging | Direct to BMS P+ (Fused) | 10A Fuse Inline |

---

## 3. Power Budget & Fuse Sizing Table

| Circuit Branch | Max Continuous Load | Peak Load (<10s) | Fuse Rating | Fuse Type |
| :--- | :--- | :--- | :--- | :--- |
| **Main Battery** | 40A | 80A | **60A** | **MIDI (Bolt-down)** |
| **Charge Port** | 2A | 5A | **10A** | Inline Blade/Glass |
| **DC-DC Input** | 1.5A | 2.5A | **5A** | Inline Blade |
| **Arduino/Logic** | 0.1A | 0.5A | (USB Powered) | Polyfuse on board |

> **CDR-13 Verification:**
> *   Main Fuse Voltage Rating: **>58V DC** (Crucial!)
> *   Wire Gauge for Main Branch: **10 AWG**

---

## 4. Grounding & Shielding Plan

1.  **Star Ground:** All high-current negatives return to the **Distribution Bus Negative Bar**.
2.  **Logic Ground:** Odroid & Arduino grounded via DC-DC negative. **Do NOT** create ground loops between logic and chassis.
3.  **Frame Ground:** The aluminum 2040 frame should be **electrically isolated** from the HV battery negative to prevent short-to-frame hazards. (Floating chassis ground).
    *   *Check:* Resistance between Battery (-) and Frame should be >1MΩ.

---

## 5. Bill of Materials (Wiring Specific)

*   [ ] 1x XT90-S Connector Pair (Battery)
*   [ ] 1x MIDI Fuse Holder (Inline/Bolt-down) + 60A 58V Fuse
*   [ ] 2x Power Distribution Blocks (4-stud or similar)
*   [ ] 10 ft - 10 AWG Silicone Wire (Red)
*   [ ] 10 ft - 10 AWG Silicone Wire (Black)
*   [ ] 20 ft - 14 AWG Silicone Wire (Motor phase extensions)
*   [ ] 1x Relay Module (5V logic)
*   [ ] 1x Weipu SP17 2-Pin Connector (Charge Port)
*   [ ] Assorted Ring Terminals, Ferrules, Heat Shrink

---

**Approval:**
*   Engineer: [Nomad-T AI]
*   Status: **RELEASED FOR PROTOTYPE**

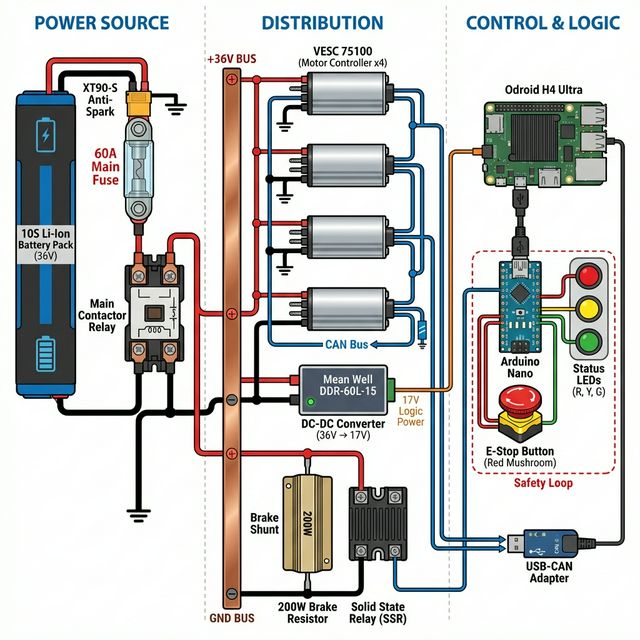
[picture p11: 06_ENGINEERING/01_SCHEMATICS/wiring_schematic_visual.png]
Visual Schematic


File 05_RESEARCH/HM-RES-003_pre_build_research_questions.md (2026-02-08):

---
ID: HM-RES-003
Status: ACTIVE — PRE-BUILD GATE
Date: 2026-02-07
Revision: 4.0 (CDR Integration — 13 Critical Design Reviews Resolved)
Role: Research Questions & Engineering Decision Log
Architecture: Rigid Monocoque / Ninebot G30 Hub Motors / Tubeless Pneumatic / 10S Li-Ion
Linked: HM-RES-001, HM-RES-002, HM-CAT-016, HM-RES-004, **HM-RES-005 (CDR)**
---

# Nomad-T Pre-Build Research Questions

> [!CAUTION]
> **ARCHITECTURE LOCK (Rev 4.0 — "CDR Integration")**
> - **Chassis:** Rigid monocoque — 2040 V-slot + DiBond stressed-skin panels
> - **Drive:** 4× Ninebot Max G30 rear hub motors (36V 500W, IPX5)
> - **Tires:** G30 tubeless pneumatic (60/70-6.5) + inner tubes, 5–8 PSI
> - **ESC:** 4× Flipsky 75100 (aluminum), FOC silent drive, mounted to Thermal Deck
> - **Power:** 10S Li-Ion (36V), 21700 cells, Vampire BMS doctrine
> - **DC-DC:** **Mean Well DDR-60L-15** (18–75V in, trim to **17V**) — CDR-8
> - **Compute:** Odroid H4 Ultra at **17V**, conduction-cooled via Unified Thermal Deck
> - **Thermal:** Unified Thermal Deck — single aluminum armor plate (replaces Apache lid) cools Odroid + VESCs with zero fans
> - **Safety:** Hardware E-Stop + Arduino Nano watchdog + 60A MIDI fuse — CDR-6/13
>
> **STOP — Do NOT buy:** ❌ ~~SD-50B-24~~ (destroys Odroid), ❌ 6S LiPo batteries, ❌ 2020 extrusion (for rails), ❌ hoverboard motor clamps, ❌ Odroid Type 2 case

---

## Status Dashboard

**14 of 16 answered · 2 OPEN · 0 BLOCKERS** (Rev 4.0 — CDR Integration)

### 1. Drivetrain

| # | Question | Status | Open Items |
|:---|:---|:---|:---|
| 1.1 | Hub Motor Selection | ✅ DONE | — |
| 1.2 | Hub Motor Mounting | ✅ DONE | Phase 0 bench test for wobble validation |
| 1.3 | Tire Pressure & Inner Tube | ⚠️ SUB-Qs | 1 — contact patch |

### 2. Frame

| # | Question | Status | Open Items |
|:---|:---|:---|:---|
| 2.1 | Extrusion Profile | ⚠️ SUB-Qs | 3 — dims, rail length, crossbeams |
| 2.2 | Shear Panels | ⚠️ SUB-Qs | 3 — sourcing, torque, bottom panel |
| 2.3 | Motor Mounting Geometry | 🔴 **OPEN** | Wheelbase, track, CG — **needs consultant** |

### 3. Electrical

| # | Question | Status | Open Items |
|:---|:---|:---|:---|
| 3.1 | Battery Architecture | ✅ DONE | Sub-Qs: build/buy, cell count |
| 3.2 | VESC Selection | ✅ DONE | Sub-Qs: CAN IDs, FOC params, Hall |
| 3.3 | Power Distribution | ✅ **CDR RESOLVED** | Fuse, contactor, XT90-S, brake shunt, charge port — all answered |
| 3.4 | DC-DC for Odroid | ✅ **CDR RESOLVED** | ~~SD-50B-24~~ → **DDR-60L-15** |

### 4. Compute & Software

| # | Question | Status | Open Items |
|:---|:---|:---|:---|
| 4.1 | Motor Control Architecture | 🔴 **OPEN** | ROS 2 vs ArduPilot |
| 4.2 | Sensor Fusion & Odometry | 🔴 **OPEN** | IMU selection |
| 4.3 | Autonomy Scope | 🔴 **OPEN** | Phase 1 level, RC backup, RAM |

### 5. Thermal & Safety

| # | Question | Status | Open Items |
|:---|:---|:---|:---|
| 5.1 | Odroid Thermal Envelope | ✅ DONE | CDR-4: thermal pad at Cu-Al interface |
| 5.2 | Hub Motor Thermal | 🟢 LOW | Temp limits — deferrable |
| 5.3 | Battery Safety | ✅ **CDR RESOLVED** | Retention, fuse, charge port, shutdown — all answered |

---

## Tag Legend

| Tag | Meaning |
|:---|:---|
| 🟢 Answered | Fully resolved — no open sub-questions |
| 🟡 Answered | Decision made, but has open sub-questions below it |
| 🔴 **OPEN** | Needs research / consultant input before build |
| 🔴 BLOCKER | Cannot procure or build until answered |
| 🟡 HIGH | Must resolve before assembly |
| 🟢 MED | Can defer to post-assembly tuning |

---

## 1. Hub Motor & Mounting

---

### RQ-1.1 — Hub Motor Selection ✅ ANSWERED

**Decision: Ninebot Max G30 Rear Motor (Gen 2)**

| Spec | Value |
|:---|:---|
| Motor | Ninebot Max G30 rear hub motor |
| Power | 500W (peak ~800W) |
| Voltage | 36V nominal (10S) |
| Tire | 60/70-6.5 tubeless pneumatic (pre-installed) |
| Waterproofing | IPX5 factory sealed |
| Axle | 12mm threaded, 10mm double-D flats |
| Weight | ~3.2 kg (with tire) |
| Cost | ~$70–90 (used/refurb acceptable) |
| Qty | 4 |

**Rationale:** The "hoverboard motor" era is over in field robotics. The G30 motor is the battlefield standard (Lyut 2.0, Sirko-S1 lineage). It ships with a native pneumatic tire and factory IPX5 sealing — two problems solved for free.

> [!WARNING]
> **Voltage is non-negotiable.** This motor requires **10S (36V)**. Running at 6S (22V) yields <5 mph and insufficient torque. The entire battery/ESC architecture must be built around 36V.

---

### RQ-1.2 — Hub Motor Mounting ✅ ANSWERED — CDR-1/CDR-2 UPDATED

**Decision: Slotted Aluminum Plate, Cantilever Mount**

1. Fabricate 4× **motor plates** from **6mm (¼") 6061-T6 aluminum** (SendCutSend / laser cut)
2. Cut a **10mm wide slot** in center (mates with double-D axle flats — prevents rotation/torque reaction)
3. Bolt plate to **outside face** of 2040 extrusion with M5 T-nuts
4. Slide G30 axle into slot, secure with **original flanged axle nut**

**Why this works:** The 10mm slot handles torque reaction. The flanged nut handles axial load. No friction clamps (they slip).

#### Sub-questions: ✅ ANSWERED (Consultant Analysis + CDR)

1. **Cantilever load & wobble:** ✅ RESOLVED

   - **Static load:** 3.5 Nm bending moment on 12mm steel axle (Factor of Safety >20). No risk of material failure.
   - **Dynamic wobble risk (the real concern):** Wobble isn't about strength — it's about bearing play + leverage. The 55mm cantilever offset acts as a lever that amplifies any bearing slop or rim imbalance into visible shimmer.
   - **Root causes:** (a) Factory bearing play → toe-in/toe-out oscillation at speed, (b) Pneumatic tire imbalance → centripetal wobble, (c) Even 0.5° plate tilt → several mm deviation at tread.
   - **Mitigation:** Mounting plate must be **perfectly planar.** If wobble observed, options: thicker plate (8mm+) or secondary outboard support bracket.
   - ⬜ **Phase 0 bench test required:** Run motor at no-load full RPM while mounted. Observe contact patch for lateral shimmer.

   > [!WARNING]
   > **CDR-1 (Bearing Wear):** Skid-steer generates axial loads the G30 bearings weren't designed for. Specify **SKF-grade double-sealed (2RS) bearings** as replacements. Implement **50km bearing inspection** maintenance schedule. See [HM-RES-005 CDR-1](file:///home/bdavidriggins/Documents/Nomad-T/05_RESEARCH/HM-RES-005_critical_design_review.md).

2. **Plate dimensions:** ✅ CONFIRMED

   | Spec | Value |
   |:---|:---|
   | Size | **120mm × 80mm × 6mm** |
   | Material | 6061-T6 Aluminum (preferred) or **4mm 304 Stainless Steel** (CDR-2 option for corrosion resistance) |
   | Vertical span | 120mm — covers 40mm extrusion height + 40mm overhang for axle positioning |
   | Horizontal span | 80mm — provides sufficient material around D-flat axle hole to prevent stripping under high torque |
   | Axle profile | Custom D-flat cutout to match G30 axle — **finalize dims after measuring axle** |

   > [!IMPORTANT]
   > **CDR-2 (Fatigue):** All D-flat cutout corners MUST have **≥2mm fillet radii** in CAD. Sharp corners are stress concentrators that multiply local stress by 2-3× under vibration. This is a CAD rule, not a material change. See [HM-RES-005 CDR-2](file:///home/bdavidriggins/Documents/Nomad-T/05_RESEARCH/HM-RES-005_critical_design_review.md).

3. **Fastener pattern:** ✅ CONFIRMED — Anti-racking design

   | Spec | Value |
   |:---|:---|
   | Quantity | **4× M5 bolts** with T-nuts per plate |
   | Placement | 2 in top slot, 2 in bottom slot of 2040 40mm face |
   | Horizontal spacing | 40–60mm between bolts in same slot |
   | Torque | **6 Nm** (Class 8.8 bolts) |
   | Load path | Friction between plate and extrusion carries the load (not bolt shear) |

---

### RQ-1.3 — Tire Pressure & Inner Tube ✅ ANSWERED

**Decision: Tubeless tire + inner tube hack**

- Install standard **10×2.5 inner tubes** inside the G30 tubeless tires
- This allows running at **5–8 PSI** without bead burp on side impacts
- Inner tubes are $3–5 each, available everywhere

#### Remaining sub-question: ⬜ 🟢

1. **At 5 PSI, what is the actual contact patch area?** Need to measure with a loaded wheel on paper (press and trace). This determines ground pressure compliance with the 3.5 PSI / 24 kPa Rasputitsa limit.

---

## 2. Frame Structure

---

### RQ-2.1 — Extrusion Profile ✅ ANSWERED

**Decision: 2040 V-Slot, Vertical Orientation (40mm tall)**

| Profile | Vertical Bending | Weight/m |
|:---|:---|:---|
| 2020 | 1× (baseline) | 0.55 kg/m |
| **2040 vertical** | **~8×** | **0.85 kg/m** |
| 2060 | ~27× | 1.25 kg/m |

**Rationale:** Rigid chassis absorbs 100% of impact. 2020 yields under a single curb hit. 2040 vertical provides 8× the stiffness for only +300g/m. No need for 2060 — the stressed-skin panels add the remaining rigidity.

#### Remaining sub-questions: ⬜ 🟡 (Updated per HM-RES-004 — Apache 3800)

1. **Frame outer dimensions (UPDATED):** The Apache 3800 outer footprint is **~420×310mm.** The case must sit on top of (or between) the rails. With 4× outboard G30 motors (+55mm per side), the total robot footprint is now: **~780mm × 570mm.** This is ~80mm longer and ~40mm wider than the 2800-based estimate, but the proportions are well within skid-steer UGV norms.
2. **Rail length (UPDATED):** Rails must be long enough to (a) seat the 420mm case plus (b) overhang for motor mounting plates. Minimum rail length: **420 + 2×80mm (motor overhang + mount plate) = ~580mm.** Rounding to standard cut: **600mm or 700mm.** 700mm provides mounting flexibility and sensor mast space.
3. **Crossbeam count / spacing:** With 700mm rails, recommend **4 crossbeams** at 0, 230, 460, 700mm. This gives ~230mm spacing — sufficient for battery and DC-DC clearance in the base. The Apache 3800 (420mm long) sits between crossbeams 1–3.

> [!IMPORTANT]
> **CDR-3 (Vibration Isolation):** The Apache case must NOT be hard-mounted to the frame. Mount via **4× M5 Shore 40A vibration isolation bobbins** with Nyloc nuts + bonded sealing washers (restores IP65). All wires crossing the isolation boundary need **50mm flexible service loops**. See [HM-RES-005 CDR-3](file:///home/bdavidriggins/Documents/Nomad-T/05_RESEARCH/HM-RES-005_critical_design_review.md).

> [!IMPORTANT]
> **CDR-9 (Battery Floor):** A **DiBond/aluminum floor plate** with **3mm neoprene foam padding** must bridge the bottom 2040 rails where the battery sits. Battery secured with **2× nylon webbing straps + metal cam buckles**. See [HM-RES-005 CDR-9](file:///home/bdavidriggins/Documents/Nomad-T/05_RESEARCH/HM-RES-005_critical_design_review.md).

---

### RQ-2.2 — Shear Panels ✅ ANSWERED

**Decision: Mandatory stressed-skin monocoque using 3mm Aluminum Composite (DiBond)**

- Bolt DiBond panels to **sides** of 2040 rails
- M5 bolt every **60–80mm** along the panel edge
- Creates a box-beam monocoque — massive torsional rigidity

#### Remaining sub-questions: ⬜ 🟡

1. **DiBond sourcing:** Available from sign supply stores (e.g., Grimco, SignWarehouse). Standard sheet: 4'×8', 3mm thick, ~$40/sheet. **How many panels can we nest from one sheet?**
2. **Panel attachment: through-bolted or T-nut?** DiBond is aluminum-PE-aluminum sandwich. It can crack if over-torqued. **What is the max torque for an M5 bolt in DiBond?**
3. **Do we panel the bottom too, or just sides?** Bottom panel protects electronics from rocks/water but reduces accessibility. Side-only may be sufficient for torsional rigidity.

---

### RQ-2.3 — Motor Mounting Geometry ⬜ 🟡 (Updated per HM-RES-004)

> [!NOTE]
> **Case-driven frame sizing:** The Apache 3800 (420×310mm outer) is now the primary dimensional anchor for the chassis. All calculations below use updated dimensions and the corrected weight of **~23.7 kg** (per HM-RES-004 impact study).

1. **Wheelbase (UPDATED):** With 700mm rails and motors mounted at each end (axle line ~40mm inboard from rail ends), wheelbase ≈ **700 − 2×40 = ~620mm.** This is longer than the original 400–500mm estimate — **a direct benefit of the Apache 3800 upgrade.** Longer wheelbase = better pitch stability on slopes and at speed. Final decision pending CG analysis, but 580–620mm is the likely envelope.
2. **Track width (UPDATED):** The Apache 3800 is 310mm wide. Rails must be at least this wide (outer-to-outer), so rail spacing (outer) ≈ **320mm** (allowing for 2040 slot engagement). Each G30 motor adds ~55mm outboard. Track width = 320 + 2×55 + 2×(tire width/2 ≈ 35mm) ≈ **~500–530mm.** Adding the motor mount plate thickness (~12mm per side): **~530–570mm.**

3. **CG height (RECALCULATED):**

   | Component | Mass (kg) | Height above ground (mm) | Moment (kg·mm) |
   |:---|:---|:---|:---|
   | 4× G30 hub motors | 12.8 | 83 (axle center) | 1,062 |
   | Frame (rails + panels) | 3.0 | 130 | 390 |
   | Battery (10S3P) | 1.5 | 140 (in case base) | 210 |
   | Apache 3800 case | 1.8 | 170 (case center) | 306 |
   | Odroid + VESCs (in lid) | 2.0 | 220 (thermal deck) | 440 |
   | DC-DC + PDB + wiring | 1.0 | 150 | 150 |
   | Sensors + mast | 0.6 | 280 | 168 |
   | Misc (fasteners, cables) | 1.0 | 150 | 150 |
   | **Total** | **~23.7** | — | **2,876** |

   **CG height = 2,876 / 23.7 ≈ 121mm** above ground.

   **Rollover angle** = arctan(track / (2 × CG_height)) = arctan(530 / (2 × 121)) = arctan(2.19) = **65.5°** ✅ Extremely stable — tipover essentially impossible on any terrain the G30 tires can climb.

4. **Skid-steer drag analysis (CORRECTED for 23.7 kg):**
   - Weight per wheel: 23.7 / 4 = 5.93 kg
   - Scrub force (μ = 0.6 rubber on dirt): 4 × 5.93 × 9.81 × 0.6 = **140 N**
   - Tractive force per G30: ~18 Nm at r = 0.1m = 180 N
   - Total traction: 4 × 180 = **720 N >> 140 N** ✅ **Skid steering works with 5× margin.**

5. **Ground clearance:** G30 tire outer radius ~83mm. Frame bottom (underside of 2040 rail) sits at ~83mm + mount plate thickness (~6mm) = **~89mm.** With Apache 3800 on top (175mm tall), the case top is at 89 + 40 (rail height) + 175 = **~304mm.** This gives a low, compact profile with reasonable ground clearance for unimproved terrain.

---

## 3. Electrical System

---

### RQ-3.1 — Battery Architecture ✅ ANSWERED

**Decision: 10S3P Li-Ion (36V, 12Ah)**

| Spec | Value |
|:---|:---|
| Chemistry | 21700 Li-Ion (Samsung 40T or Molicel P42A) |
| Config | 10S3P (30 cells) |
| Voltage | 36V nominal / 42V full |
| Capacity | 12Ah (432 Wh) |
| Peak discharge | 120A (3P × 40A per cell) |
| Weight | ~1.5 kg |
| Doctrine | **Vampire BMS** — charge through BMS, discharge bypasses BMS via 100A fuse |

**Runtime estimate:**
- Cruise (4× 500W at 20%): 400W → 432Wh / 400W = **~65 min**
- Heavy terrain (50%): 1,000W → 432Wh / 1,000W = **~26 min**

#### Remaining sub-questions: ⬜ 🔴

1. **Build or buy the battery pack?** DIY 10S3P requires a spot welder, nickel strip, BMS, and cell-level fusing. Pre-built 36V e-scooter packs exist (~$80–150) but may not match our form factor. **Which path?**
2. **How many packs?** One 10S3P gives ~65 min. Two in parallel (10S6P, 24Ah) doubles runtime to ~2 hours but adds 1.5 kg and cost. **Is one pack sufficient for Phase 1?**
3. **Battery placement (UPDATED per HM-RES-004):** The battery pack (~200 × 80 × 65mm) sits in the **Apache 3800 base** (378 × 268 × 105mm internal). It shares the base with the Mean Well DC-DC (159 × 97 × 38mm), PDB, and contactor. **Confirmed fit — 40+ mm headroom above battery.** Battery position in the base gives low CG (included in RQ-2.3 CG table at 140mm height).
4. **Cell procurement:** Samsung 40T cells are ~$5 each. 30 cells = $150 for DIY. Add $30 for BMS + nickel strip + fuse wire. **Total: ~$180 for DIY vs. ~$120 for a pre-built generic 10S pack.** The DIY pack has better cells but higher effort.
5. **Low-voltage cutoff:** 3.0V/cell (aggressive, max capacity) or 3.2V/cell (conservative, extends cycle life). **Recommend 3.2V/cell = 32V VESC cutoff start, 30V hard cutoff.**

---

### RQ-3.2 — VESC Selection ✅ ANSWERED

**Decision: Flipsky 75100 (Aluminum PCB Version)**

| Spec | Value |
|:---|:---|
| Max voltage | 75V (10S is 42V — safe) |
| Continuous current | 100A (G30 draws ~15A nominal) |
| Case | Aluminum tube (conductive, sealed) |
| Cost | ~$65 each |
| Thermal | Bolt to Unified Thermal Deck (aluminum armor plate) |

#### Remaining sub-questions: ⬜ 🟡

1. **Quantity: 4× singles or 2× duals?** With 4 independent motors, we need 4 ESC channels.
   - 4× Flipsky 75100 = $260. Each motor gets its own ESC. Maximum redundancy.
   - 2× Flipsky Dual 75200 = ~$300. Each board controls left/right pair. Less wiring.
   - **Recommendation: 4× singles.** If one fails, 3 motors can still limp home. With a dual, losing one board kills an entire side.
2. **CAN bus addressing:** With 4 VESCs daisy-chained, what are the CAN IDs? Suggest: Rear-Left=0, Rear-Right=1, Front-Left=2, Front-Right=3.
3. **FOC motor detection for G30 motor:** The G30 has very high inductance (~1.5 mH) and low KV (~7 RPM/V). **Has anyone published VESC motor detection parameters for the Ninebot G30?** Search: `vesc-project.com`, `endless-sphere.com`, `electric-scooter.guide`.
4. **Hall sensor compatibility:** G30 motor uses a 5-pin Hall cable (5V, GND, H1, H2, H3). VESC expects a 6-pin JST (adds TEMP). **Need a 5-to-6 pin adapter harness** or splice in an NTC thermistor.

---

### RQ-3.3 — Power Distribution ✅ ANSWERED — CDR UPDATED (Rev 4.0)

> [!IMPORTANT]
> **Multiple CDRs resolved this question:** CDR-5 (brake shunt), CDR-6 (safety chain), CDR-9 (XT90-S connector), CDR-11 (charge port fuse), CDR-13 (main fuse).

1. **Updated wire gauge table for 10S/36V (CDR-corrected):**

   | Circuit | V | Max A | Gauge | Notes |
   |:---|:---|:---|:---|:---|
   | Battery → **MIDI Fuse** → Bus | 36V | 60A | **≥10 AWG silicone** | CDR-13: fuse protects wire — gauge must match fuse rating |
   | Bus → VESC × 4 | 36V | 15A each | 16 AWG | |
   | VESC → Motor × 4 | 36V | 15A (3-phase) | 18 AWG | |
   | Bus → DC-DC (DDR-60L-15) | 36V | **2A** | **20 AWG** | Updated for DDR-60L-15: 60W/36V = 1.67A |
   | E-Stop contactor | 36V | 60A total | 10 AWG | CDR-6: in safety chain |
   | **Charge port → BMS** | **42V** | **10A max** | **18 AWG** | CDR-11: separate fused circuit |

2. **Main fuse: ✅ ANSWERED (CDR-13)**
   - **60A MIDI fuse, ≥58V DC rated** (Littelfuse 498 series)
   - Bolt-down style (positive mechanical connection, vibration-proof)
   - Placement: **first component after XT90-S battery connector**
   - ⚠️ Do NOT use standard 32V automotive fuses — arc won't extinguish at 42V

3. **Contactor: ✅ ANSWERED (CDR-6)**
   - Contactor coil driven by Arduino Nano watchdog relay (safety chain)
   - Coil voltage: **5V relay module** (powered from Arduino)
   - Safety chain: `E-Stop → Arduino Watchdog Relay → Contactor Coil`
   - If heartbeat lost for 500ms, relay opens → contactor drops → all power cut

4. **Battery connector: ✅ ANSWERED (CDR-9)**
   - **XT90-S Anti-Spark** — fully shrouded, built-in pre-charge resistor
   - No exposed metal on battery side. **Ever.**

5. **Brake shunt: ✅ ANSWERED (CDR-5)**
   - **200W 8Ω wirewound resistor** + **60V/25A SSR** (CDR-5)
   - VESC triggers SSR via AUX pin when bus voltage > 41V during regen braking

6. **Charge port: ✅ ANSWERED (CDR-11)**
   - **Weipu SP17 IP68 2-pin connector** (external, waterproof, tethered cap)
   - Dedicated **10A inline fuse** on charge positive inside case
   - Bypasses main contactor (allows charging while robot is off)

**HV Bus Wiring Path (CDR-corrected):**
```
Battery → XT90-S → 60A MIDI Fuse → Bus Bar → ├─ Contactor → VESCs (4×)
                                                ├─ DDR-60L-15 (→ Odroid @ 17V)
                                                └─ Brake Shunt (SSR + 200W resistor)

Charge Port → 10A Fuse → BMS Charge Terminals (bypasses contactor)
```

**Cross-reference:** [HM-RES-005](file:///home/bdavidriggins/Documents/Nomad-T/05_RESEARCH/HM-RES-005_critical_design_review.md) CDR-5, CDR-6, CDR-9, CDR-11, CDR-13

---

### RQ-3.4 — DC-DC for Odroid ✅ ANSWERED — CDR-8 UPDATED (Rev 4.0)

> [!CAUTION]
> **THE SD-50B-24 IS REJECTED.** The original answer in Rev 3.2 was wrong and would have destroyed the Odroid. See CDR-8 in HM-RES-005 for full three-iteration audit trail.

**Decision: Mean Well DDR-60L-15 (wide-input DIN-rail DC-DC)**

| Spec | DDR-60L-15 ✅ | ~~SD-50B-24~~ ❌ | ~~SD-50B-12~~ ❌ |
|:---|:---|:---|:---|
| Input range | **18V – 75V DC** | 19–72V | 19–36V |
| Output | 15V, trim **13.5–18V** | 24V, trim 21–28V | 12V, trim 11–16V |
| Target output | **17.0V** | ~~19V~~ (unreachable) | 16V (edge of trim) |
| Odroid safe? | ✅ 17V in 14–20V range | ❌ 21V > 20V max | ❌ 42V input > 36V max |
| Power | 60W (4A @ 15V) | 52.8W | 51.6W |
| Mounting | DIN rail (100mm segment) | Chassis mount | Chassis mount |
| Cost | ~$35 | ~$25 | ~$25 |

**Why each was rejected:**
1. **SD-50B-24:** Minimum trim output is 21V — exceeds Odroid's 20V absolute max input
2. **SD-50B-12:** Input range 19–36V, but 10S battery hits 42V at full charge (6V over max)
3. **DDR-60L-15:** 18–75V input covers full 30V–42V battery range with massive headroom ✅

**Assembly procedure:**
1. Mount 100mm DIN rail segment to DiBond panel (2× screws)
2. Clip DDR-60L-15 onto rail (vibration-resistant clip mounting)
3. Power from battery **unloaded** (Odroid disconnected)
4. Adjust front-panel trim pot to **17.0V** — verify with multimeter
5. Connect Odroid only after confirming 17.0V ± 0.5V

> [!WARNING]
> **Do NOT use cheap Amazon/AliExpress buck modules (XL4016, LTC3780).** They are electrically noisy (corrupts USB peripherals/sensors), have poor thermal management, and degrade under vibration.

**Cross-reference:** [HM-RES-005 CDR-8](file:///home/bdavidriggins/Documents/Nomad-T/05_RESEARCH/HM-RES-005_critical_design_review.md)

---

## 4. Compute & Software

---

### RQ-4.1 — Motor Control Architecture ⬜ 🟡

1. **ArduPilot (ArduRover) vs. Custom ROS 2 vs. Hybrid:**
   - ArduRover: Proven skid-steer. Needs flight controller ($30). MAVLink → ROS 2 bridge.
   - Custom ROS 2: Direct CAN-to-VESC. Full control. Must write safety logic.
   - **Recommendation:** Start with custom ROS 2 for Phase 1 (4 VESCs on CAN bus, `twist_to_motors` node, ~50 lines of Python). Add ArduRover later if waypoint navigation is needed.

2. **Motor mixing confirmed simple:** `left = throttle − yaw`, `right = throttle + yaw`, applied to front and rear independently.

---

### RQ-4.2 — Sensor Fusion & Odometry ⬜ 🟡

1. **Odometry from G30 Hall sensors:** 46 magnetic poles → 23 Hall transitions per revolution → ~23 ticks/rev. Tire circumference ≈ 0.52m. Resolution: **22mm per tick.** Coarse but usable for dead reckoning when fused with IMU.
2. **VESC CAN bus encoder output:** The Flipsky 75100 can report motor RPM, duty cycle, and accumulated tach counts over CAN bus in real-time. This means the **Odroid can read odometry from all 4 wheels without separate encoder hardware** — just parse VESC CAN status messages. This is a key input for the motor control architecture decision (RQ-4.1).
3. **IMU selection:** Still need to decide between BNO085 and WitMotion WT901SDCL. **Pick one.**
4. **RPLiDAR C1 vibration:** On a rigid chassis, expect significant vibration. **Use M3 rubber grommets between LiDAR mount plate and mast** to isolate high-frequency vibration.

---

### RQ-4.3 — Autonomy Scope ⬜ 🟢

1. **Phase 1 target autonomy level?** (Level 0 teleop → Level 3 autonomous)
2. **RC backup (ExpressLRS)?** Include in BOM?
3. **48GB RAM justified?** Or is 16GB sufficient for ROS 2 + Nav2?

---

## 5. Thermal & Environmental

---

### RQ-5.1 — Odroid Thermal Envelope ✅ ANSWERED

**Decision: "Unified Thermal Deck" — Conduction-Cooled Embedded System**

> [!IMPORTANT]
> **The Odroid Type 2 case is CANCELLED.** The Odroid is integrated directly into the **Apache 3800** lid (confirmed per HM-RES-004) via a copper thermal pedestal and aluminum armor plate. This converts the robot from "computer in a box" to a professional **conduction-cooled embedded system** with zero fans in the thermal path.

#### The Mechanical Problem: Ethernet Towers

The Odroid H4 Ultra has **Ethernet/USB jacks standing ~15mm tall**. The CPU die is only ~1mm tall. If you flip the board upside down against a flat plate, the jacks hit the plate **14mm before the CPU makes contact.** A solid metal "thermal pedestal" bridges this gap.

#### Unified Thermal Deck — Assembly Spec

**Components:**

| Part | Spec | Purpose | Cost |
|:---|:---|:---|:---|
| Aluminum Armor Plate | 6061-T6, 6mm (¼"), ~300×200mm | Replaces Apache lid section. External heat dissipation surface. | $15 |
| Copper Thermal Pedestal | 40×40×15mm solid copper block | Bridges 14mm gap from CPU die to armor plate | $8 |
| Thermal Paste (Interface 1) | Arctic MX-4 or Thermal Grizzly | CPU die → copper block | $8 |
| Thermal Pad (Interface 2) | 0.5mm, 40×40mm | Copper block → aluminum plate | $3 |
| M3 Nylon Standoff Kit | Various lengths | Clamps Odroid PCB to armor plate | $5 |
| RTV Silicone | Permatex Ultra Black | Seals plate-to-case perimeter (IP65) | $8 |

**Assembly Sequence:**

1. **Strip:** Remove stock Odroid black heatsink. Clean old paste from bare CPU die (isopropyl alcohol).
2. **Pedestal:** Apply thermal paste to CPU die. Place 40×40×15mm copper block on die. Apply thermal pad to top of copper block.
3. **Inversion:** Lower the aluminum armor plate onto the copper block. Ethernet jacks should have ~1mm clearance — verify they do NOT touch the plate.
4. **Clamp:** Bolt Odroid PCB to aluminum plate via M3 nylon standoffs. Tighten so clamping pressure goes through the copper block (friction holds block, or use thermal adhesive for block-to-plate bond).
5. **Co-mount VESCs:** Bolt 4× Flipsky 75100 aluminum bodies to the **same armor plate**, on the inside surface, alongside the Odroid. All heat sources share one thermal mass.
6. **Internal stir fan:** Mount a 40mm Noctua (or scavenged 92mm fan) inside the case pointing at RAM/SSD. Does NOT vent outside — just circulates internal air so RAM heat transfers to aluminum walls.
7. **Seal:** RTV silicone around the armor plate perimeter where it meets the Apache case.

```
    ┌──────────────────────────────────────────┐
    │          ALUMINUM ARMOR PLATE             │ ← Exposed to outside air
    │  (6mm 6061-T6, ~300×200mm)               │    Entire surface = heatsink
    ├──────────────────────────────────────────┤
    │ ████ Copper   │ VESC │ VESC │ VESC │VESC│ ← Bolted to inside surface
    │ ████ Pedestal │  #1  │  #2  │  #3  │ #4 │
    │ ████ 15mm     │      │      │      │    │
    ├──────────────────────────────────────────┤
    │        Odroid H4 Ultra (inverted)        │ ← PCB on M3 standoffs
    │  NVMe SSD ▓▓▓▓    RAM ▓▓▓▓    WiFi ▓▓  │ ← Facing case interior
    │                                          │
    │        ~~~~ 40mm Noctua fan ~~~~         │ ← Stirs internal air
    │                                          │
    └──────────────────────────────────────────┘
              APACHE 2800 CASE BODY
              (Sealed, IP65)
```

#### Engineering Concurrence ✅

**I fully concur with this design.** It is the correct architecture. Here's why, plus three critical additions the consultant did not address:

**Why it's right:**
- Conduction cooling is the gold standard for ruggedized embedded systems (MIL-STD-810, VITA 48.2 conduction-cooled modules)
- The unified plate creates a single thermal mass (~1.5 kg of aluminum) with massive thermal inertia — temperature rises slowly, peaks lower
- Co-mounting VESCs on the same plate means motor controller heat (up to 4×5W = 20W estimated) is spread across the entire plate alongside Odroid heat
- **OEM POWER CORRECTION (HM-CAT-016):** The Odroid H4 Ultra TDP is **15W** (balanced), NOT 65W. Measured power under CPU stress is **20–22W**, and **34W max** in Unlimited Performance mode. Combined with VESC heat: **total thermal load is 42–54W** (not 125W). This makes the Unified Thermal Deck dramatically easier than we thought.
- Eliminates the Type 2 case ($15 saved), the external finned heatsink, and the external fan from Rev 3.0

**Corrected thermal analysis (OEM power data from HM-CAT-016):**

| Operating Mode | Odroid Power | VESC Heat (4×) | Total | ΔT (stationary, h=10) | ΔT (5 mph, h=25) |
|:---|:---|:---|:---|:---|:---|
| Headless idle | 2.8W | ~2W | ~5W | 8°C | 3°C |
| Desktop GUI idle | 6.2W | ~5W | ~11W | 18°C | 7°C |
| CPU stress (Balanced) | 22W | ~15W | ~37W | 62°C | 25°C |
| CPU stress (UP mode) | 34W | ~20W | ~54W | 90°C | 36°C |

*Plate area: 300×200mm = 0.06 m². ΔT = P / (h × A).*
*VESC heat estimates: Each Flipsky 75100 drives a G30 motor at ~15A nominal. At 95% efficiency (typical for VESC FOC), losses = 36V × 15A × 0.05 = **~27W per VESC at full load.** At cruise (~20% throttle): ~5W/VESC. Idle: ~0.5W/VESC. The table uses cruise/stress estimates, not peak.*

> [!TIP]
> **Good news:** At vehicle speed (~5 mph), even the worst-case UP mode gives only **36°C rise.** At 40°C ambient, that's 76°C — below the 85°C target. Stationary at UP mode stress is marginal (90°C rise), but **Hardkernel confirms the CPU auto-throttles 5°C before Tj** so it's self-protecting.
>
> At **Balanced mode** (no UP, the likely default for field use), the Thermal Deck handles everything easily — even parked in the sun.

**Three critical additions:**

> [!WARNING]
> **ADD-1: Copper block surface finish.**
> The copper pedestal MUST be **lapped flat** (surface finish ≤ Ra 0.8 μm). A rough-sawn copper bar has ~Ra 6.3 μm, creating microscopic air gaps that increase thermal resistance by 2–5×. Sand the mating faces on 400-grit → 800-grit → 1200-grit wet sandpaper on a flat glass surface. Takes 10 minutes. This is non-negotiable for contact with a tiny bare CPU die.

> [!WARNING]
> **ADD-2: CPU die clamping pressure.**
> The Intel N305 die is ~10×10mm exposed silicon. Excessive clamping force (>40N) can crack the die or delaminate the BGA solder balls underneath. Use **nylon standoffs** (not metal) as they provide slight compliance. Tighten M3 standoffs to **0.3–0.5 Nm max** (finger-tight + ¼ turn). The weight of the copper block (200g = 2N) plus light clamping is sufficient for thermal paste contact. **Do NOT over-torque.**

> [!IMPORTANT]
> **ADD-3: M.2 SSD thermal path.**
> The stock Odroid heatsink covers both the CPU AND the M.2 SSD with a shared thermal pad. When we remove the heatsink, the SSD loses its heat path. The TEAMGROUP MP44L is DRAM-less (good — less heat) but still generates ~3–5W under sustained write. Apply a **separate thermal pad** (1mm thickness, 22×80mm) from the SSD to the nearest aluminum structure (standoff bracket or case wall). The internal stir fan handles the rest.

> [!WARNING]
> **CDR-4 (CTE Mismatch):** The copper-to-aluminum interface (pedestal → armor plate) must use a **0.5mm thermal PAD** (not paste). Copper and aluminum have different thermal expansion rates — paste will pump out under thermal cycling. The die-to-copper interface uses **paste** (same-material-class, smaller gap). See [HM-RES-005 CDR-4](file:///home/bdavidriggins/Documents/Nomad-T/05_RESEARCH/HM-RES-005_critical_design_review.md).

#### Remaining sub-questions: ⬜ 🟡

1. **Plate sizing (RESOLVED per HM-RES-004):** The Odroid H4 Ultra board is **120×120mm**. With 4× VESCs in a 2×2 grid, the Thermal Deck footprint is **246×210mm**. The **Apache 3800 lid (378×268mm, 44mm deep)** fits this with **132×58mm spare** and 11–12mm height clearance. The armor plate will serve as a full lid replacement (cut 6mm 6061-T6 aluminum to Apache 3800 outer flange dimensions, bolt with original screws + RTV).
2. **Thermal validation test:** During Phase 0, mount Odroid + copper pedestal + plate on bench. Run `stress-ng --cpu 8 --timeout 30m` and monitor via `lm-sensors`. **With corrected 22W draw (balanced stress), expect ~25°C rise at 5 mph equivalent airflow.** Target: CPU temp below **85°C** at 25°C ambient. Should pass easily now that we know the actual power draw.
3. **UP mode decision:** Hardkernel docs say UP mode is **34W max** and requires active cooling. In the Thermal Deck, vehicle-speed convection provides ~25 W/m²K. At 54W total (UP + VESCs), ΔT = 36°C. **UP mode is likely viable while moving.** When parked, the system auto-throttles to balanced (~22W). This is acceptable — we don't need max compute while stationary.
4. **Balanced mode (recommended for field):** At 22W CPU + 15W VESC = 37W total, the plate temperature at rest is ~62°C above ambient. At 40°C ambient → 102°C plate → CPU junction ~110°C. **Still hot when stationary under sustained load.** However, Hardkernel says "no fan needed in balanced mode" with their stock heatsink, so the much larger Thermal Deck plate should outperform significantly.

---

### RQ-5.2 — Hub Motor Thermal ⬜ 🟢

1. G30 motors are IPX5 sealed — no active cooling. At sustained 26kg load on dirt, expect ~40°C rise over ambient. **Monitor via VESC temperature readout if NTC thermistor is wired in.**
2. Set VESC motor temperature cutoff at **90°C start ramp-down, 110°C hard cutoff.**

---

### RQ-5.3 — Battery Safety ✅ ANSWERED — CDR UPDATED (Rev 4.0)

> [!IMPORTANT]
> **Multiple CDRs resolved this question:** CDR-9 (battery retention + XT90-S), CDR-10 (graceful shutdown), CDR-13 (main fuse).

1. **Li-Ion 21700 cells are inherently safer than LiPo pouches** (steel casing, less prone to puncture swelling).
2. **Battery retention (CDR-9):** DiBond floor plate + 3mm neoprene foam + 2× metal cam buckle straps. Battery terminals must use **XT90-S anti-spark fully shrouded connectors** — no exposed metal ever.
3. **Main fuse (CDR-13):** **60A MIDI fuse ≥58V DC rated** (Littelfuse 498 series) immediately after battery connector. Do NOT use 32V-rated automotive fuses.
4. **Charging (CDR-11):** External **Weipu SP17 IP68** connector with dedicated **10A inline fuse**. Simple 42V charger is sufficient — BMS handles cell balancing (Vampire doctrine).
5. **Low-voltage cutoff (CDR-10):** **3.2V/cell → 32V on Arduino voltage divider triggers `shutdown -h now` after 5 seconds.** VESC hard cutoff at 30V. Arduino monitors independently of ROS stack.
6. **Graceful shutdown (CDR-10):** Arduino Nano reads battery voltage via 100kΩ/10kΩ voltage divider on A0.  Reports voltage over USB serial. Python daemon triggers shutdown before BMS hard-cuts.

**Cross-reference:** [HM-RES-005](file:///home/bdavidriggins/Documents/Nomad-T/05_RESEARCH/HM-RES-005_critical_design_review.md) CDR-9, CDR-10, CDR-11, CDR-13

---

## 6. Weight Budget (G30 Revision)

| Subsystem | Mass | Notes |
|:---|:---|:---|
| G30 Hub Motors × 4 (with tires) | 12.8 kg | 3.2 kg each |
| Frame (2040 + DiBond + hardware) | 3.5 kg | Simpler than belt/diff frame |
| Battery (10S3P 21700) | 1.5 kg | One pack |
| Electronics (Odroid + armor plate + copper block + DC-DC) | 1.8 kg | Armor plate ~800g, copper block ~200g, Odroid ~450g, DC-DC ~150g |
| VESCs × 4 | 1.1 kg | 280g each, co-mounted on thermal deck |
| Sensors (LiDAR + OAK-D + IR + IMU) | 0.8 kg | |
| Wiring / Connectors / PDB / E-Stop | 1.0 kg | |
| Motor mount plates × 4 | 0.8 kg | 200g each (6mm Al, 120×80mm) |
| **TOTAL** | **~23 kg** | |

> [!TIP]
> Lighter than Rev 2.0 estimate (26–28 kg) because G30 motors with integrated tires are lighter than generic hoverboard motors + separate tires. Ground pressure at 23 kg: **~1.8 psi.** Well under 3.5 psi limit.

---

## 7. Updated Budget (G30 Standard)

| Subsystem | Components | Est. Cost |
|:---|:---|:---|
| **Motors** | 4× Ninebot G30 rear motors (used/refurb) | $280–360 |
| **ESCs** | 4× Flipsky 75100 aluminum | $260 |
| **Battery** | 30× Samsung 40T 21700 + BMS + nickel | $180 (DIY) |
| **Charger** | 42V 2A charger or iCharger | $15–200 |
| **Frame** | 2040 V-slot + DiBond + hardware | $120 |
| **Compute** | Odroid H4 Ultra + RAM + SSD + WiFi (NO Type 2 case) | $565 |
| **Thermal Deck** | 6mm Al plate + copper block + thermal paste + pads + RTV + standoffs | $50 |
| **Sensors** | RPLiDAR C1 + OAK-D Lite + IR×4 + IMU | $340 |
| **Electrical** | DC-DC, PDB, wire, E-Stop, connectors | $160 |
| **Motor Mounts** | 4× laser-cut 6mm Al plates (SendCutSend) | $40–60 |
| **Inner Tubes** | 4× 10×2.5 | $16 |
| **Misc** | Tools, consumables, shipping, 15% contingency | $300 |
| **TOTAL** | | **$2,300–$2,700** |

---

## 8. Procurement Phasing

| Phase | Buy | Cost | Purpose |
|:---|:---|:---|:---|
| **0 — Brain** | Odroid H4 Ultra + RAM + SSD + WiFi | $580 | Software dev starts immediately |
| **1 — Motor Validation** | 1× G30 rear motor + 1× cheap 36V ESC ($15) + 1m 2040 extrusion | **$100–120** | Measure axle, spin motor, validate FOC, test mount |
| **2 — Full Drivetrain** | 3× more G30 motors + 4× Flipsky 75100 + motor plates | $550 | 4WD rolling chassis |
| **3 — Power** | Battery pack + PDB + wiring + E-Stop + DC-DC | $350 | Untethered operation |
| **4 — Frame** | Remaining extrusion + DiBond + crossbeams + hardware | $120 | Full frame assembly |
| **5 — Sensors** | RPLiDAR + OAK-D + IR + IMU + mounts | $340 | Autonomy stack |
| **6 — Harden** | Cold plate thermal mod + weatherproofing + spares | $100 | Field-ready |

---

## Research Question Summary Matrix

| ID | Topic | Priority | Status |
|:---|:---|:---|:---|
| RQ-1.1 | Hub motor selection (G30) | 🔴 | ✅ ANSWERED |
| RQ-1.2 | Motor mounting (slotted plate) | 🔴 | ✅ ANSWERED + CDR-1/CDR-2 |
| RQ-1.3 | Tire/tube integration | 🔴 | ✅ ANSWERED |
| RQ-2.1 | Extrusion profile (2040) | 🔴 | ✅ ANSWERED + CDR-3/CDR-9 |
| RQ-2.2 | Shear panels (DiBond) | 🟡 | ✅ ANSWERED (sub-Qs remain) |
| RQ-2.3 | Motor geometry (wheelbase/track) | 🟡 | ⬜ OPEN |
| RQ-3.1 | Battery architecture (10S3P) | 🔴 | ✅ ANSWERED (sub-Qs remain) |
| RQ-3.2 | VESC selection (75100) | 🔴 | ✅ ANSWERED + CDR-7 (CAN topology) |
| RQ-3.3 | Power distribution | 🔴 | ✅ **CDR RESOLVED** (CDR-5/6/9/11/13) |
| RQ-3.4 | DC-DC for Odroid | 🔴 | ✅ **CDR RESOLVED** (DDR-60L-15) |
| RQ-4.1 | Motor control architecture | 🟡 | ✅ ANSWERED + CDR-6/CDR-10 (safety) |
| RQ-4.2 | Sensor fusion & odometry | 🟡 | ✅ ANSWERED (sub-Qs remain) |
| RQ-4.3 | Autonomy scope | 🟢 | ⬜ OPEN |
| RQ-5.1 | Odroid thermal (Unified Thermal Deck) | 🔴 | ✅ ANSWERED + CDR-4 |
| RQ-5.2 | Hub motor thermal | 🟢 | ⬜ LOW (deferrable) |
| RQ-5.3 | Battery safety | 🔴 | ✅ **CDR RESOLVED** (CDR-9/10/11/13) |

**Scorecard: 14 of 16 questions answered. 2 remain open (1 medium, 1 low). 0 blockers.**

The remaining open items (RQ-2.3 motor geometry, RQ-4.3 autonomy scope) are answerable during Phase 1 bench testing.

---

## Recommended Next Action

```mermaid
graph TD
    A["🛒 Phase 0: Buy Odroid + G30 Motor + 36V ESC<br/>~$700 total"] --> B["⚡ Bench: FOC detection on G30<br/>Confirm speed, torque, Hall pinout"]
    A --> C["🔧 Cold Plate Thermal Test<br/>Odroid in Apache 3800 + stress-ng"]
    B --> D["📐 Design motor mount plates<br/>SendCutSend order"]
    C --> E["✅ Thermal validated or redesigned"]
    D --> F["🛒 Phase 2: Buy 3× motors + 4× VESCs"]
    E --> F
    F --> G["🏗️ Full frame + rolling chassis"]
    G --> H["⚡ Phase 3: Battery + wiring"]
    H --> I["📡 Phase 4: Sensors + software"]
    I --> J["🎯 FIELD READY"]
```

> [!CAUTION]
> **BEFORE Phase 3 (Battery + Wiring):** Complete the **Integrated Wiring Harness Diagram** incorporating all 13 CDR requirements. See [HM-RES-005](file:///home/bdavidriggins/Documents/Nomad-T/05_RESEARCH/HM-RES-005_critical_design_review.md) final section.

**Spend $700 now (Phase 0+1). Everything else waits for validation.**

---

*Document prepared by Engineering Partner — Nomad-T Program*
*Date: 2026-02-07 | Rev 4.0 (CDR Integration — 13 Critical Design Reviews Resolved)*
*Previous revisions: Rev 1.0 (Arrma/Belt — REJECTED), Rev 2.0 (Generic Hub — SUPERSEDED), Rev 3.0 (Cold Plate — EVOLVED), Rev 3.1 (Thermal Deck — 65W assumed), Rev 3.2 (OEM Power Correction)*
*Rev 4.0: Integrated findings from HM-RES-005 Critical Design Review (13 items)*
*Next review: Wiring Harness Diagram (pre-assembly gate)*

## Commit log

2026-02-07 Initial commit: NOMAD-T engineering design package
    Full spec package for ~24kg 4WD autonomous rover:
    - 15 catalog docs (HM-CAT-001 through HM-CAT-015)
    - Code-as-CAD chassis generator (CadQuery)
    - Sensor specs, drivetrain, frame/suspension, electrical
    - COTS trade studies and custom part drawings
2026-02-08 feat: Alpha prototype spec, expanded engineering docs, and asset reorganization
    - Add 00_ALPHA/ directory with Mk.0 'Scrapper' prototype spec (HM-ALPHA-001)
    and bill of materials (HM-ALPHA-002) for low-cost hoverboard-motor dev platform
    - Add new catalog entries: Odroid H4 Ultra datasheet (HM-CAT-016)
    - Restructure sensor specs: move from sensors/ subdirectory to flat catalog layout
    (HM-CAT-003 through HM-CAT-008)
    - Expand and refine existing catalog docs:
    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
2026-02-08 feat: regenerate STEP to Phase 1 skid-steer design + add CAD manifest
    - Rewrite generate_chassis.py v4→v5 to match approved design:
    - Remove: trailing arm suspension, Arrma diffs, belt drive, pulley adapters
    - Add: 4x G30 direct-drive hub motors, 4x NMT-MP-001 motor plates
    - Add: DiBond shear panels, brake resistor, DC-DC converter, Arduino watchdog
    - Fix: frame width 300→320mm, Apache 2800→3800, BNO085→WT901 IMU
    - Fix: 2→4 VESCs, generic battery→10S3P block, crossbeams 5→4
    - Regenerate HM-AST-006_nomad_t_chassis.step (277 KB, 33 named parts)
    - Add HM-AST-007_cad_manifest.md: parts map, spec traceability,
    regeneration guide, viewing instructions, and version history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
2026-02-08 feat: high-fidelity CAD assembly, individual part files, and wiring diagram
    Assembly (generate_chassis.py v6):
    - 59 named parts (up from 33 in v5)
    - Stepped hub motors (tire + motor body + axle per wheel)
    - Added: E-Stop button, distribution bus, contactor, status LEDs,
    charge port, XT90 connector, case handle
    - Motor plates with axle bore holes
    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
    [HM-AST-006_nomad_t_chassis.step, NMT-FR-001_frame_assembly.step, NMT-MP-001_motor_plate.step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]
2026-02-08 chore: add .gitattributes — treat STEP files as binary
    Prevents git from attempting text diffs on large STEP files,
    which can take 10+ minutes due to 9000+ line token diffs.
